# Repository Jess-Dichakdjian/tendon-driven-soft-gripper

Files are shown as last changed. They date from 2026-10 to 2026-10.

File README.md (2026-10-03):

# Tendon-Driven Soft Robotic Gripper

**Three-finger soft robotic gripper with antagonistic tendon actuation, silicone molding, suction-assisted grasping and pressure sensing**

Academic soft-robotics project focused on the design, fabrication and experimental validation of a compliant gripper capable of adapting to rigid, irregular, deformable and wet objects.

> **Status:** Completed academic team project  
> **Team size:** 6  
> **Main areas:** Soft robotics, mechanical design, silicone molding, tendon actuation, pressure sensing, prototyping and experimental validation

---

## At a Glance

| | |
|---|---|
| **Architecture** | Three soft silicone fingers arranged radially |
| **Actuation** | Six antagonistic tendons driven through a coaxial double-spool mechanism |
| **Control complexity** | One rotational input coordinates all three fingers |
| **Finger behaviour** | Active bidirectional bending |
| **Additional adhesion** | Palm-mounted silicone suction cup |
| **Sensing** | Suction-line pressure sensing |
| **Fabrication** | FDM-printed molds/frame + cast silicone fingers |
| **Materials** | Ecoflex 00-35 FAST and Dragon Skin 10 |
| **Testing** | Grasping, coordination, suction assistance and submerged-object retrieval |

---

# Project Overview

The objective was to develop a **three-finger soft robotic gripper** capable of secure and adaptive grasping across different object geometries and environmental conditions.

The design combined several complementary mechanisms:

```text
Soft Silicone Fingers
        +
Antagonistic Tendons
        +
Coaxial Double-Spool
        +
Palm Suction Cup
        +
Pressure Sensing
```

The resulting prototype was designed to support:

- external enveloping grasps
- internal expanding grasps
- irregular-object grasping
- deformable-object handling
- misaligned approaches
- suction-assisted holding
- wet and submerged object manipulation

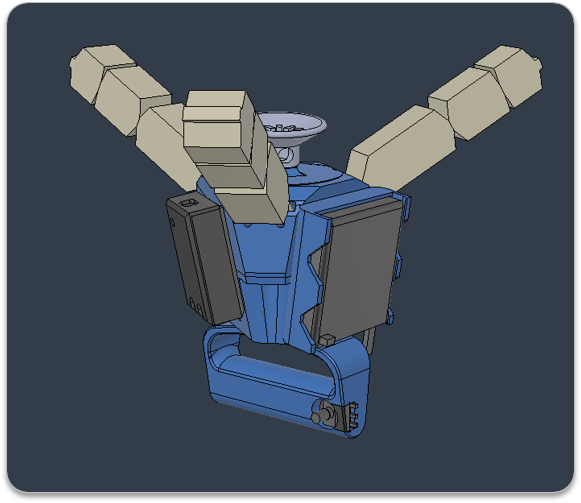
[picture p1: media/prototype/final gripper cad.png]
Final gripper CAD


[▶ View final gripper actuation](<media/prototype/final gripper actuation video.mp4>)

---

# My Contributions

This was a **six-person academic team project**.

My main contributions were:

### Concept & Prototyping

- contributed to the overall gripper concept and manipulation approach
- participated in iterative physical prototyping
- assisted with 3D printing of several prototype components
- contributed to final mechanical assembly

### Mold Preparation & Soft Fabrication

I took primary responsibility for the **mold-preparation stage**, including:

- preparing the molds before casting
- inserting cable guides / routing features
- applying mold-release treatment
- supporting the silicone casting process
- tendon/cable insertion after fabrication

### Pressure-Sensing System

I took primary responsibility for the **pressure-sensing subsystem**, from integration through working prototype testing.

The sensor was used to provide information about suction pressure and seal quality.

The implemented prototype used this as sensing/monitoring information.

A proposed future extension is to use the pressure signal in closed-loop control:

```text
Suction Pressure
      ↓
Detect Loss of Seal
      ↓
Increase Finger Grasp
      ↓
Reduce Risk of Object Drop
```

This automatic feedback behaviour was a **future-control concept**, not part of the final implemented controller.

### Experimental Validation

I participated with the team in the full experimental testing programme, including:

- finger motion testing
- three-finger coordination
- adaptive grasping
- suction-assisted grasping
- irregular and deformable object tests
- wet/submerged-object tests

---

# Mechanical Architecture

The gripper uses **three soft silicone fingers positioned approximately 120° apart**.

Each finger is designed for compliant bending and object adaptation.

The main mechanical elements are:

```text
Rigid 3D-Printed Frame
        │
        ├── Soft Finger ×3
        │     ├── Tendon A
        │     └── Tendon B
        │
        ├── Coaxial Double Spool
        │
        ├── Servo Actuation
        │
        └── Palm Suction Cup
              │
              └── Pressure Sensor
```

The soft fingers provide compliant contact, while the tendon mechanism provides active bending in both directions.

---

# Antagonistic Tendon Actuation

Each finger contains two antagonistic tendons.

The concept is analogous to opposing biological muscle groups:

```text
Tendon A pulls
     ↓
Finger bends in one direction

Tendon B pulls
     ↓
Finger bends in the opposite direction
```

A coaxial double-spool mechanism winds one tendon set while releasing the opposing set.

This allows:

- active flexion
- active extension
- coordinated finger motion
- low actuator count
- mechanical underactuation

One rotational input controls all six tendons and coordinates the three fingers.

[▶ View final gripper actuation](<media/prototype/final gripper actuation video.mp4>)

---

# Soft Finger Design

The finger geometry was designed to support large deformation while maintaining sufficient structural stability.

Important design features included:

- tapered finger geometry
- segmented finger structure
- bidirectional bending
- compliant silicone body
- rigid mounting at the finger base
- textured contact surfaces

The finger design also incorporated **hexagonal surface microstructures** inspired by biological wet-adhesion systems.

These textures were intended to help channel fluid away from the contact region and improve grip under wet conditions.

---

# Silicone Material Strategy

Two silicone materials were combined during fabrication.

### Ecoflex 00-35 FAST

Used for greater compliance and deformation.

### Dragon Skin 10

Used to provide additional structural support and shape stability.

The fabrication approach combined both materials to balance:

```text
Compliance
    ↕
Structural Stability
```

---

# Mold-Based Fabrication

The fingers were produced using custom 3D-printed molds.

The fabrication process included:

```text
CAD Mold Design
      ↓
3D Printing
      ↓
Cable-Guide Preparation
      ↓
Mold Release
      ↓
Silicone Mixing
      ↓
Separate Casting
      ↓
Partial Curing
      ↓
Mold Combination
      ↓
Final Curing
      ↓
Demolding
      ↓
Flash Removal
      ↓
Tendon Insertion
```

## Mold Preparation

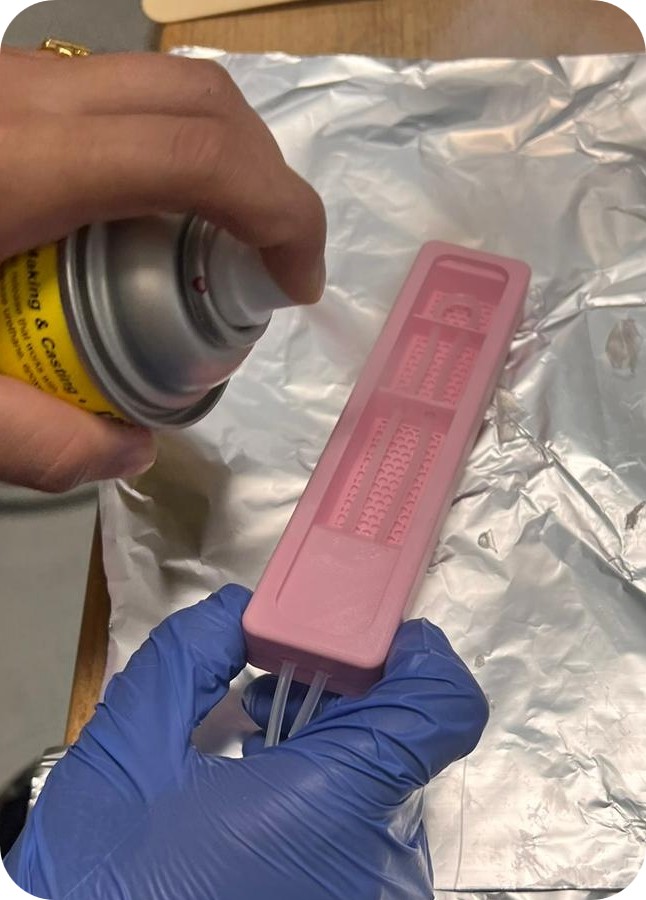
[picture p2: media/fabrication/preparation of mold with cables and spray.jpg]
Mold preparation


Cable guides were inserted to constrain tendon routing and reduce friction before the silicone was cast.

## Silicone Mixing

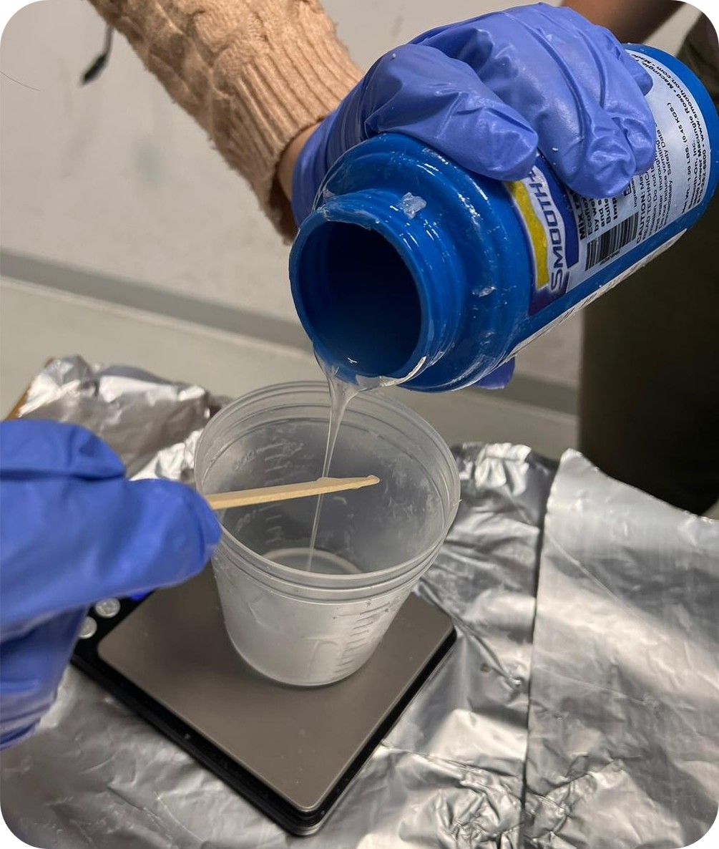
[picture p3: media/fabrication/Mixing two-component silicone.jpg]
Silicone mixing


## Two-Material Casting

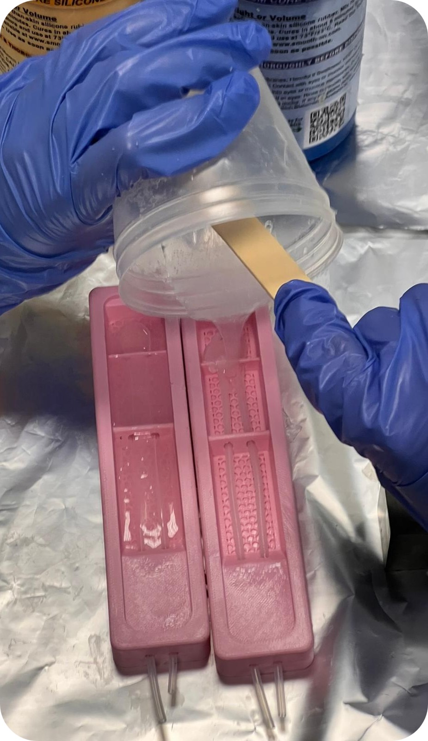
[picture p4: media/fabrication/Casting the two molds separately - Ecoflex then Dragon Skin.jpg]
Ecoflex and Dragon Skin casting


## Final Curing

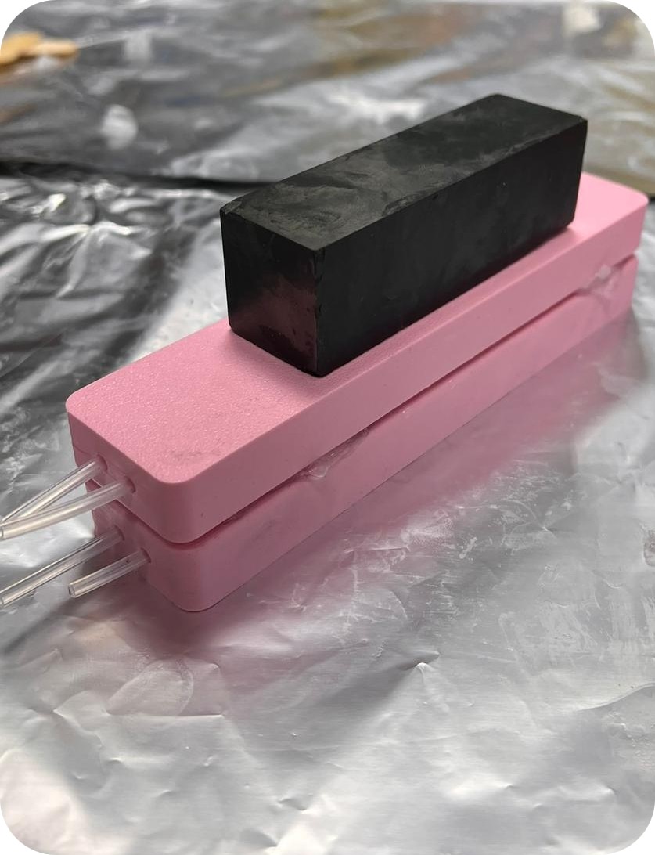
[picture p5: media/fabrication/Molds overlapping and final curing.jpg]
Molds overlapping for final curing


## Demolded Finger

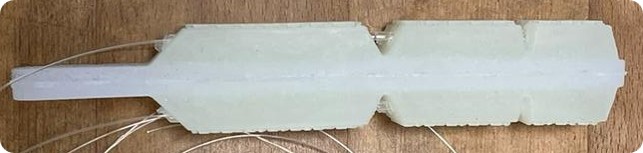
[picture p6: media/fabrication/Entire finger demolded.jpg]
Demolded soft finger


---

# Palm Suction System

A compliant silicone suction cup was integrated into the palm to complement the finger grasp.

The two mechanisms serve different roles:

```text
Soft Fingers
    ↓
Distributed Contact
+
Shear Stability

Suction Cup
    ↓
Normal Adhesion
```

When a suitable seal is formed, the suction cup provides additional resistance to pull-off forces.

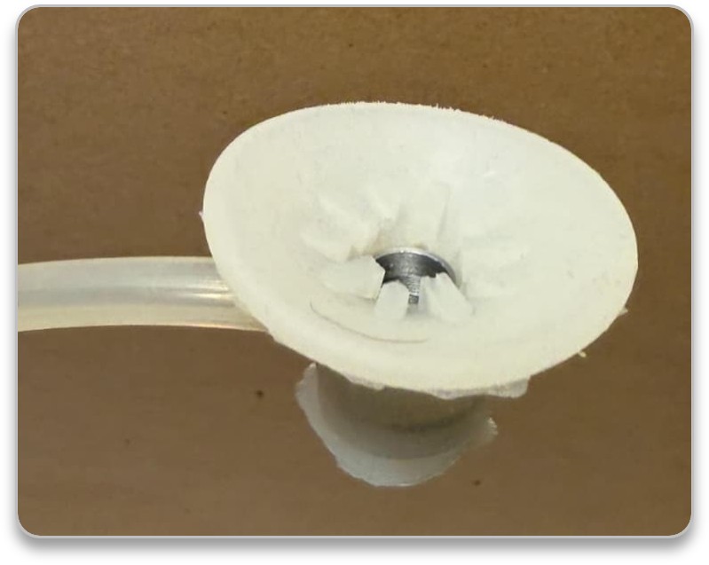
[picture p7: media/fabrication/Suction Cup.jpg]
Suction cup


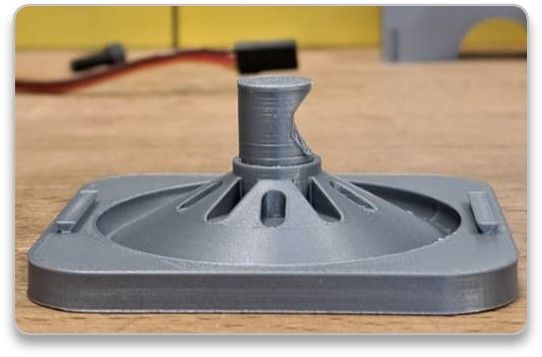
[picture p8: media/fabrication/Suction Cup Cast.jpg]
Cast suction cup


[▶ View suction-cup mold / fabrication concept](<media/fabrication/Suction Cup Casting exploded view.mp4>)

---

# Pressure Sensing

The suction line includes a pressure sensor.

The implemented sensing system provided information about the pressure level and therefore the quality of the suction seal.

This is particularly useful because suction performance depends strongly on:

- object geometry
- surface roughness
- contact alignment
- leakage
- seal quality

The pressure sensing worked on the physical prototype.

The current system uses the reading primarily as information.

A future closed-loop version could use pressure loss as a control trigger:

```text
Pressure Drop
     ↓
Possible Seal Loss
     ↓
Command Stronger Finger Closure
     ↓
Maintain Object Stability
```

That automatic response was **not implemented in the final prototype**.

---

# CAD & Mechanical Design

The repository includes both native SolidWorks files and a STEP export.

```text
cad/
├── solidworks/
│   ├── base.SLDPRT
│   ├── mold_fingers_fill_patt_v3_noBump.SLDPRT
│   ├── mold_fingers_fill_patt_v3_noBump_FINGER.SLDPRT
│   ├── molds_preview.SLDASM
│   └── soft_project_assembly.SLDASM
│
└── step/
    └── AssemblySoft.step
```

The STEP model provides a more software-independent representation of the mechanical assembly.

## Final CAD

Final gripper CAD

## Frame / Internal Layout

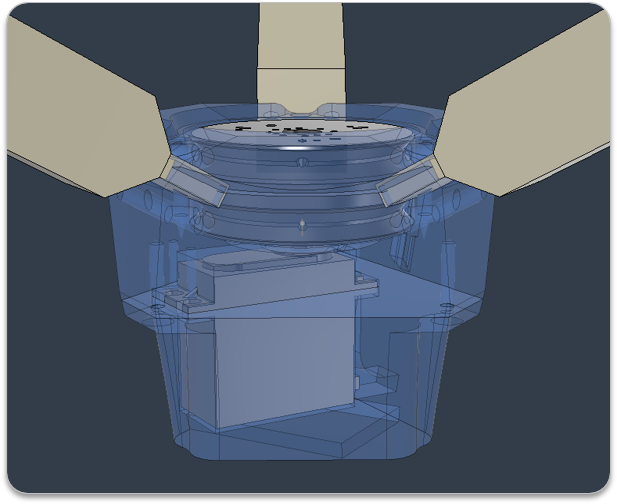
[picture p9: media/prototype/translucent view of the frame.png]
Translucent frame view


[▶ View exploded assembly animation](<media/prototype/final gripper exploded view.mp4>)

---

# Experimental Validation

Testing focused on verifying the gripper's key functional behaviours.

---

## 1. Bidirectional Finger Motion

The antagonistic tendons were tested for:

- flexion
- extension
- return toward neutral
- repeatability under repeated commands

The mechanism successfully demonstrated active bidirectional bending.

---

## 2. Three-Finger Coordination

The double-spool transmission was tested to verify whether all three fingers moved together under a single rotational input.

Evaluation focused on:

- simultaneous motion onset
- consistent opening/closing direction
- final finger curvature
- inter-finger timing differences

The prototype achieved coordinated three-finger motion.

Minor asymmetry was observed due to tendon friction and pretension differences.

---

# Adaptive Grasping Tests

Several grasp configurations were tested.

## External Enveloping Grasp

[▶ External enveloping grasp](<media/testing/EXTERNAL ENVELOPING GRASP.mp4>)

## Internal Expanding Grasp

[▶ Internal expanding grasp](<media/testing/INTERNAL EXPANDING GRASP.mp4>)

## Deformable / Flexible Object

[▶ Deformable-object test](<media/testing/DEFORMABLE-FLEXIBLE OBJECT.mp4>)

## Irregular Object

[▶ Irregular-object test](<media/testing/IRREGULAR OBJECT.mp4>)

## Misaligned Approach

[▶ Misaligned grasp approach](<media/testing/MISALIGNED APPROACH.mp4>)

These experiments demonstrated how compliance allows the fingers to adapt to shape and alignment variation without requiring exact geometric contact planning.

---

# Suction-Assisted Grasping

The palm suction cup was evaluated as an auxiliary adhesion mechanism.

[▶ Suction-assisted grasping](<media/testing/Suction-Assisted Grasping.mp4>)

The tests showed that suction can complement the soft fingers when an adequate seal is available.

The fingers contribute distributed contact and lateral stability, while suction contributes additional normal adhesion.

---

# Wet / Submerged Testing

Wet manipulation was an important target scenario because the finger texture and suction concept were inspired partly by biological attachment mechanisms.

## Single Object Retrieval

[▶ Single submerged-object retrieval](<media/testing/Single submerged object retrieval.mp4>)

## Multiple Object Retrieval

[▶ Multiple submerged-object retrieval](<media/testing/Multiple submerged object retrieval.mp4>)

The prototype was able to perform submerged grasping demonstrations using the compliant fingers and textured contact surfaces.

---

# Validation Against Design Objectives

| Objective | Outcome |
|---|---|
| Active bidirectional bending | ✅ Achieved |
| One-input three-finger coordination | ✅ Achieved |
| Adaptive grasping across different geometries | ✅ Achieved |
| Suction-assisted holding | ✅ Achieved |
| Physical silicone-finger fabrication | ✅ Achieved |
| Wet/submerged grasp demonstrations | ✅ Demonstrated |
| Working pressure sensing | ✅ Implemented |
| Automatic pressure-based grasp tightening | ❌ Future work |
| Quantitative grasp-force validation | ❌ Not performed |
| Closed-loop autonomous suction control | ❌ Not implemented |

The project therefore demonstrated the proposed low-complexity hybrid grasping architecture while also identifying clear areas for further development.

---

# Limitations

The prototype exhibited several expected limitations of tendon-driven soft systems.

### Tendon Transmission Variability

Cable friction, slack and pretension differences can create:

- small delays
- asymmetric finger motion
- different final curvatures

### Fabrication Variability

Manual silicone fabrication can introduce:

- bubbles
- mold tolerances
- material inconsistencies
- bending asymmetry

### Suction Seal Dependence

Suction performance depends strongly on contact geometry and seal quality.

### Primarily Qualitative Validation

Testing demonstrated functional success, but the project did not include a full quantitative benchmark of:

- grasp force
- payload capacity
- pull-off force
- bending angle
- success rate
- cycle durability

---

# Future Work

The clearest next steps are:

### Closed-Loop Pressure Feedback

Use the existing pressure sensing as feedback for automatic grasp adaptation:

```text
Pressure falls
    ↓
Detect reduced suction
    ↓
Increase finger tension
    ↓
Maintain grasp
```

### Automatic Vacuum Generation

Replace the manually driven suction source with a compact controllable pump.

### Improved Tendon Routing

Add:

- lower-friction guides
- adjustable tensioners
- better cable anchoring

### More Repeatable Silicone Fabrication

Potential improvements include:

- improved mold tolerances
- vacuum degassing
- standardized curing
- more repeatable material dosing

### Quantitative Testing

Future experiments should measure:

- bending angle
- grasp force
- payload
- suction pull-off force
- grasp success rate
- repeatability
- durability over repeated cycles

---

# Repository Structure

```text
tendon-driven-soft-gripper/
│
├── README.md
│
├── cad/
│   ├── solidworks/
│   └── step/
│
├── docs/
│   └── presentation/
│
└── media/
    ├── fabrication/
    ├── prototype/
    └── testing/
```

---

# Project Presentation

The final team presentation is included here:

```text
docs/presentation/Group 2 - Soft Robotics Project Submission-compressed.pdf
```

It contains the complete project development process, design rationale, manufacturing workflow and testing programme.

---

# Skills Demonstrated

This project provides evidence of experience in:

- soft robotics
- mechanical prototyping
- tendon-driven actuation
- compliant mechanisms
- underactuated robotic systems
- SolidWorks
- CAD
- FDM 3D printing
- mold design
- silicone casting
- Ecoflex
- Dragon Skin
- tendon routing
- mechanical assembly
- pressure sensing
- suction systems
- sensor integration
- experimental testing
- wet-environment manipulation
- robotic grasping
- design iteration
- hardware integration

---

# Team Work & Attribution

This repository represents a **six-person academic team project**.

The complete system, CAD, prototype and validation programme were developed collaboratively.

The **My Contributions** section above identifies the areas in which I had direct responsibility or significant hands-on involvement.

In particular, I took primary responsibility for:

- mold preparation
- tendon/cable insertion support
- pressure-sensor integration and testing

and contributed to:

- project concept development
- physical prototyping
- 3D printing
- assembly
- experimental validation

Electronics and actuator-control development were primarily handled by other team members, with limited input from me.

---

# Project Status

✅ **Completed academic soft-robotics project**

The physical prototype was fabricated and successfully demonstrated:

- active bidirectional finger motion
- coordinated three-finger actuation
- adaptive grasping
- suction-assisted holding
- pressure sensing
- wet/submerged object retrieval

The next development stage would focus on **closed-loop sensing and control, improved fabrication repeatability and quantitative performance evaluation**.

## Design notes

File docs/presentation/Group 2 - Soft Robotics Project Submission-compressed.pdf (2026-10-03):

# Soft Robotics – Final project

Presented by (Group 2)
Andrea Radicetti
Ege Sarp Dengizmen
Giulia Papini
Jessica Dichakdjian
Tommaso Servillo
Tony Al Helou

Presented to
Professor Barbara Mazzolai Tommaso Scudeletti
Presented on
23/07/2026

# INTRODUCTION

2

# Project Overview

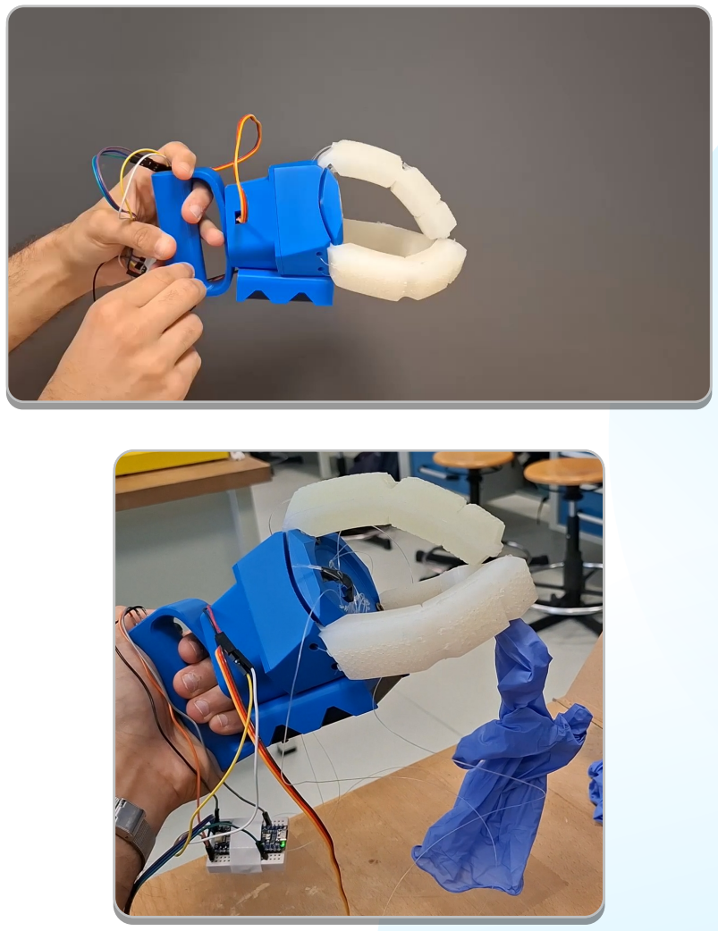
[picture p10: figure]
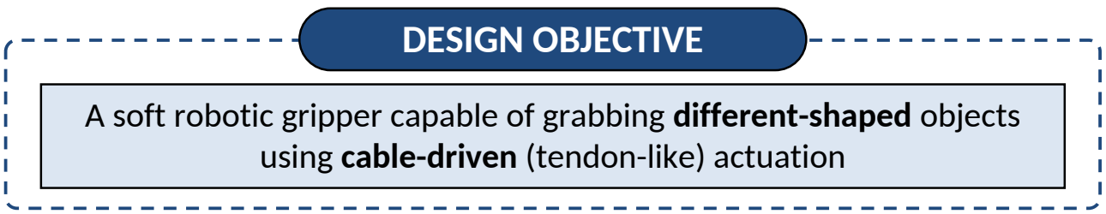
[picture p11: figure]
using cable-driven (tendon-like) actuation; DESIGN OBJECTIVE

A soft robotic gripper capable of grabbing different-shaped objects

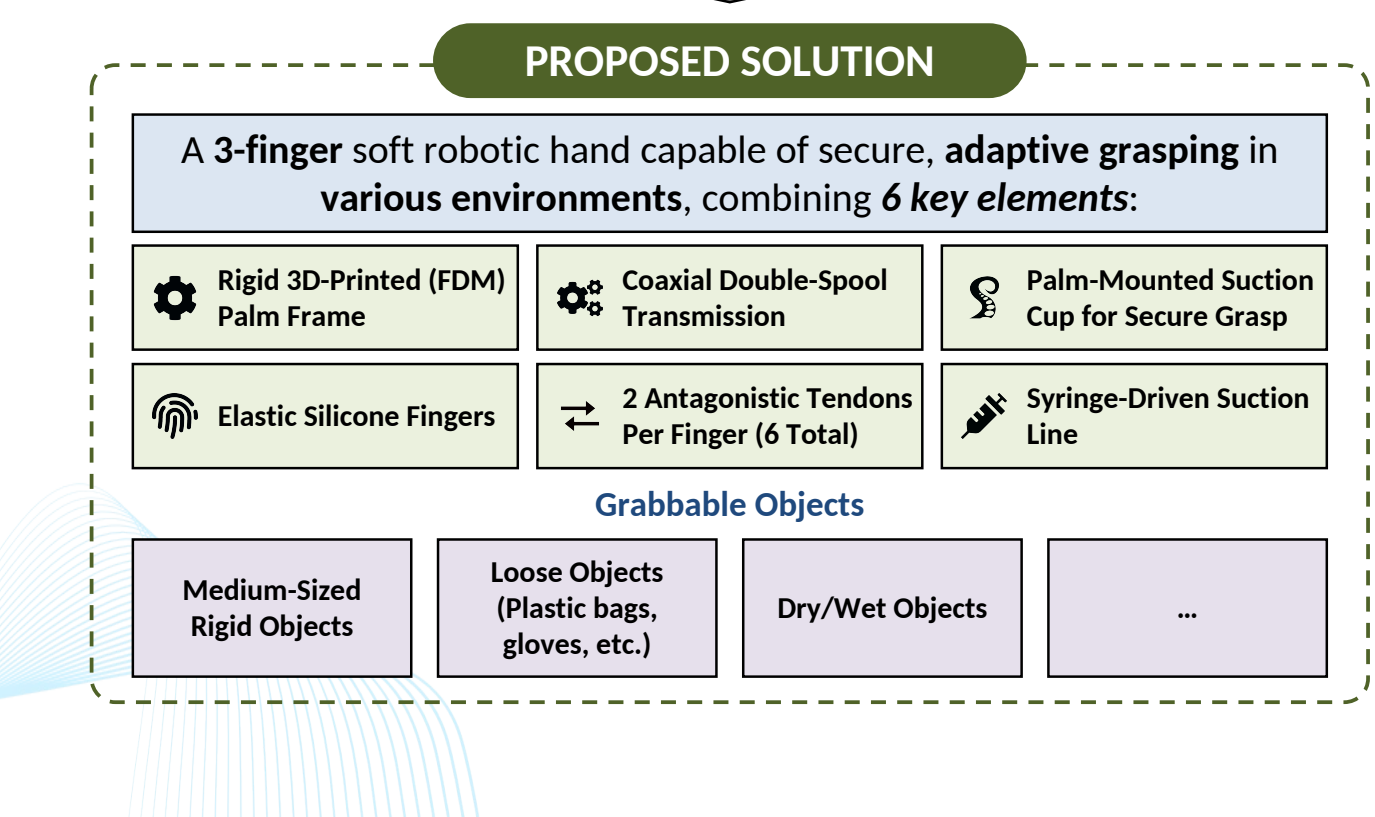
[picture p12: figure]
Medium-Sized Rigid Objects; Loose Objects (Plastic bags, gloves, etc.); Dry/Wet Objects; PROPOSED SOLUTION; Rigid 3D-Printed (FDM) Palm Frame; Coaxial Double-Spool Transmission; Palm-Mounted Suction Cup for Secure Grasp; Elastic Silicone Fingers; 2 Antagonistic Tendons; Per Finger (6 Total); Syringe-Driven Suction Line; Grabbable Objects

A 3-finger soft robotic hand capable of secure, adaptive grasping in various environments, combining 6 key elements:

3

# Why use Soft Grasping?

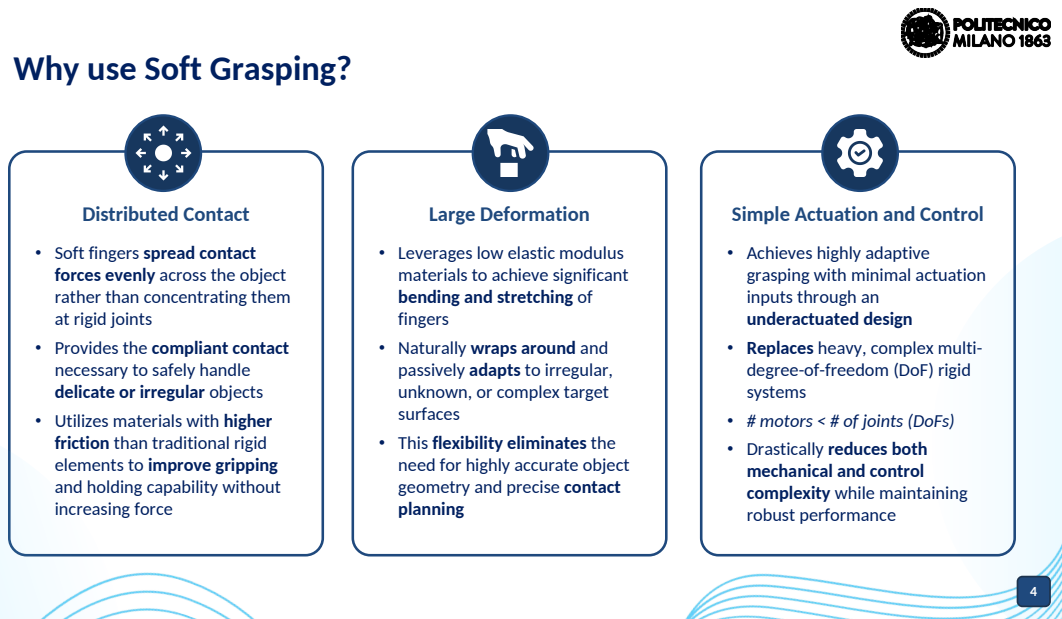
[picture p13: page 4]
Distributed Contact; Large Deformation; Simple Actuation and Control

• Soft fingers spread contact
forces evenly across the object
rather than concentrating them
at rigid joints
• Provides the compliant contact
necessary to safely handle
delicate or irregular objects
• Utilizes materials with higher
friction than traditional rigid
elements to improve gripping
and holding capability without
increasing force

• Leverages low elastic modulus
materials to achieve significant
bending and stretching of
fingers
• Naturally wraps around and
passively adapts to irregular,
unknown, or complex target
surfaces
• This flexibility eliminates the
need for highly accurate object
geometry and precise contact
planning

• Achieves highly adaptive
grasping with minimal actuation
inputs through an
underactuated design
• Replaces heavy, complex multi-
degree-of-freedom (DoF) rigid
systems
• # motors < # of joints (DoFs)
• Drastically reduces both
mechanical and control
complexity while maintaining
robust performance

# STATE OF THE ART

5

# State of the Art – Tendon-Driven Soft Fingers

Working
Principle
- Transmits forces from a motor by shortening or lengthening flexible cables routed directly through the silicone fingers (in series or parallel)
- Produces natural, adaptive bending and grasping around diverse geometries
- Eliminates the need for rigid joint linkages or internal skeletons for each finger

Trade-offs &
Limitations
- Hosting cable tensioning motors outside the soft structure provides a fast response with low system inertia, weight, and volume
- Forces subject the elastomeric fingers to friction, mechanical wear, and physical tear – tendon elasticity wears down -> hysteresis and creep
- Highly nonlinear (no universal formula)

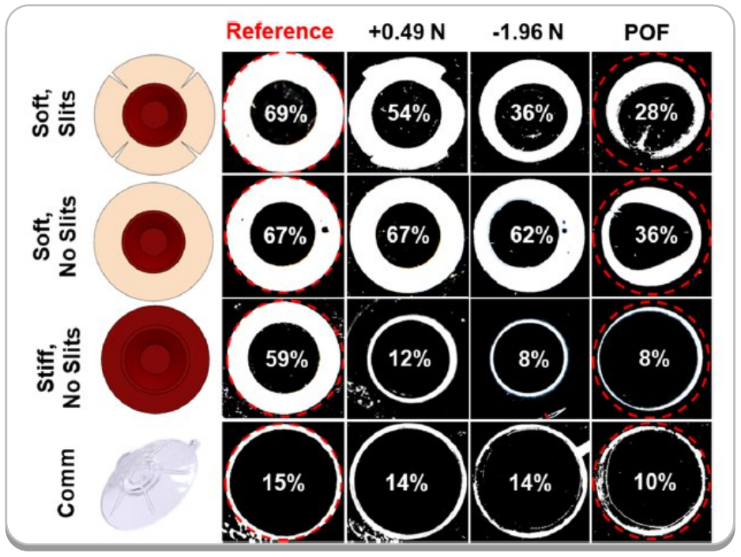
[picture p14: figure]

[“Reversible adhesion to rough surfaces both in and out of water, inspired by the clingfish suction disc”, J.A.Sandoval et al., 2019]

# State of the Art – Suction Cup

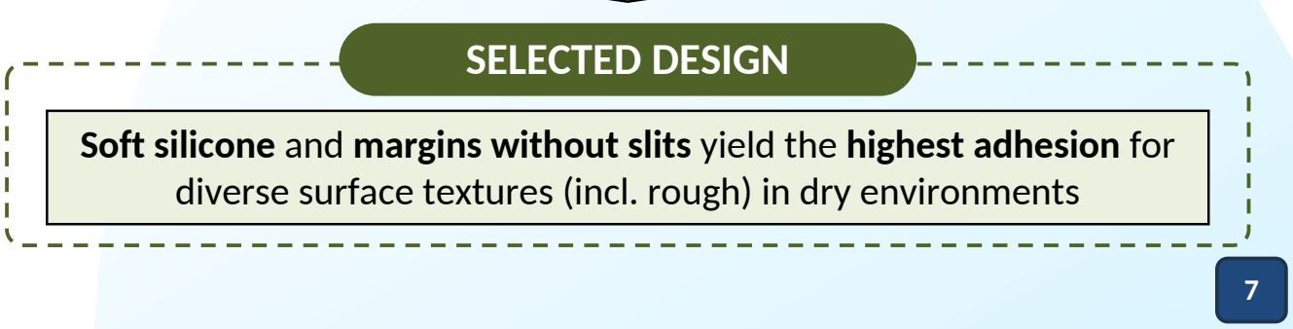
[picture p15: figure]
SELECTED DESIGN

Soft silicone and margins without slits yield the highest adhesion for diverse surface textures (incl. rough) in dry environments

Adhesion is generated through a pressure differential between the inner cavity and the surrounding environment

Performance varies depending on the design parameters

The suction cup is pressed against the object to expel fluid or air from the internal chamber and initiate the attachment seal
Functions as an additional adhesion mechanism that complements the gripping forces of the fingers, and can adapt to surface shape and curvature as long as the radial margins/boundaries are firmly sealed
Suction Cup Geometry | Margin Slits | Material Stiffness | …

WORKING PRINCIPLE

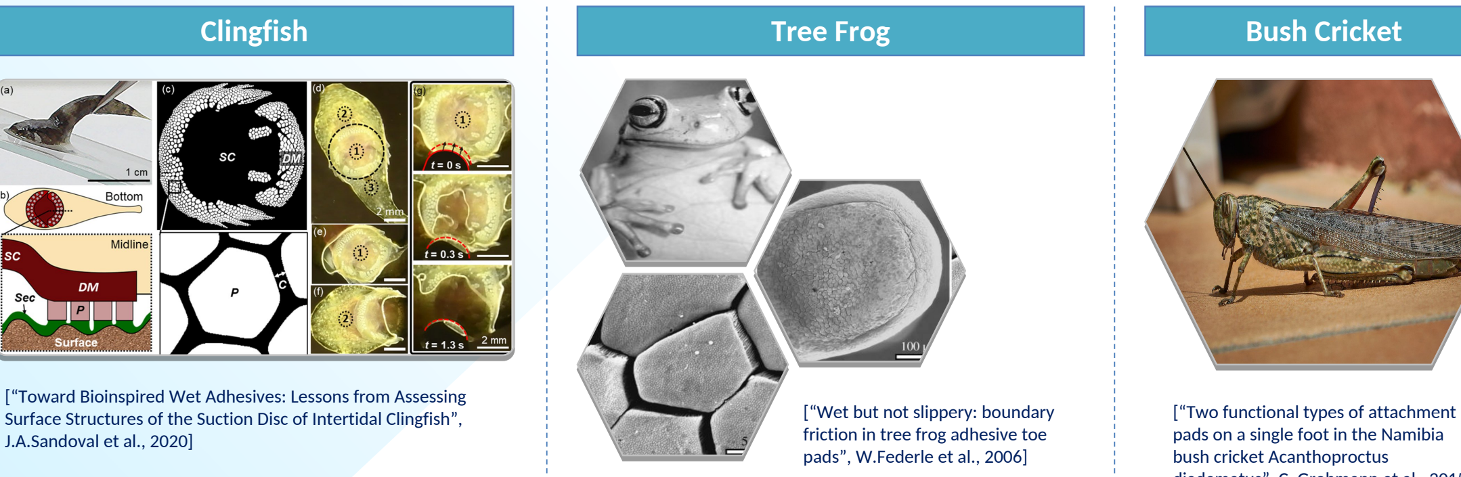
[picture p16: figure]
J.A.Sandoval et al., 2020]; Clingfish; Bush Cricket; [“Wet but not slippery: boundary friction in tree frog adhesive toe pads”, W.Federle et al., 2006]; Tree Frog; [“Two functional types of attachment pads on a single foot in the Namibia bush cricket Acanthoproctus
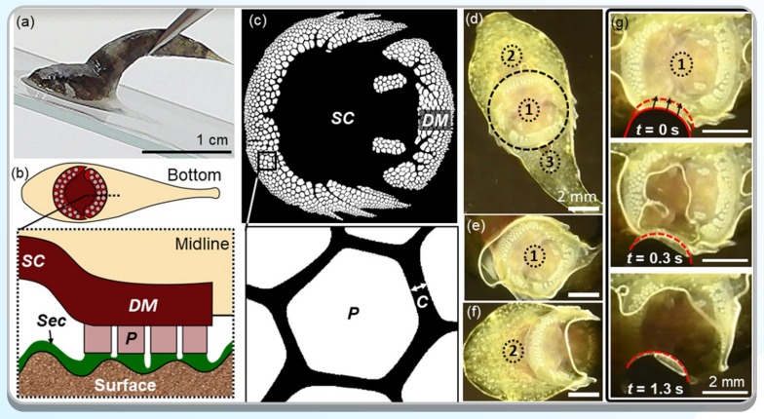
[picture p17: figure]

[“Toward Bioinspired Wet Adhesives: Lessons from Assessing Surface Structures of the Suction Disc of Intertidal Clingfish”,

8

# State of the Art – Hexagonal Surface Textures

Biological
Inspiration
- Hexagonal microstructures are found on the attachment pads of the clingfish, tree frog, and bush-cricket
- Channels away boundary fluids from surfaces through micro-grooves between hexagon shapes to prevent hydrodynamic lubrication (hydroplaning) and the formation of a slippery lubricating fluid film
- They allow animals to maintain a secure, high-friction contact interface even when fully submerged or interacting with highly lubricated wet objects

diadematus”, C. Grohmann et al., 2015]

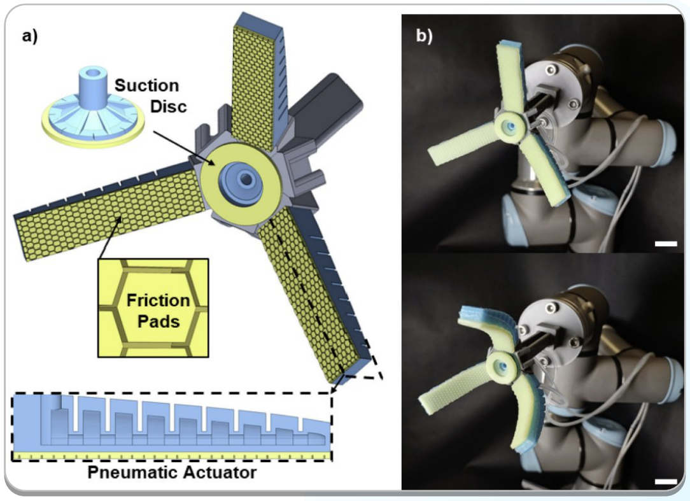
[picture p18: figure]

[“Combining Suction and Friction to Stabilize a Soft Gripper to Shear and Normal Forces, for Manipulation of Soft Objects in Wet Environments”, J.A.Sandoval et al., 2022]
9

# State of the Art – Combination of Soft Gripper and Suction

CHALLENGING WET ENVIRONMENTS Boundary fluids act as a lubricant between soft fingers and
target surfaces, reducing friction and causing hydrodynamic
slipping during object manipulation HYBRID APPROACH
- Combination of texture micro-channels and central palm suction cup to divert boundary fluids and re-establish direct between fingers and surface material
- Two complementary force mechanisms where the suction cup handles normal pull-off resistance and the fingers provide lateral shear stability
Approach achieves higher tolerance under combined normal and shear loads than either suction or soft fingers can provide alone

# DESIGN

10

# From reference to our idea

STARTING POINT | OUR IDEA IMPLEMENTATION

11

Underactuated soft gripper: tendon-driven soft finger, one motor, one DOF, passive elastic recovery.

Bio-inspired design solutions: suction disk (like clingfish) with surface texture for enhanced grip + shape of human finger

Palm suction cup for enhanced grasping reliability.

Hexagonal texture on finger surfaces for improved wet grip.

Three-finger gripper with two antagonistic tendons per finger → active bidirectional bending (via Double-spool mechanism).

# Design - Finger

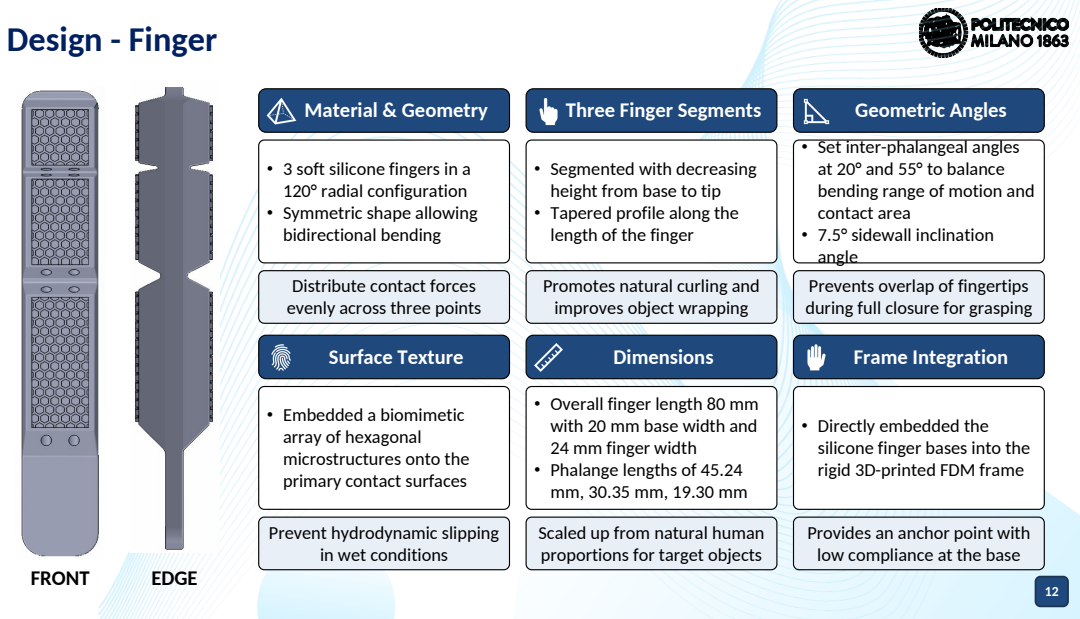
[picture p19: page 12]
FRONT; EDGE

Material & Geometry
• 3 soft silicone fingers in a
120° radial configuration
• Symmetric shape allowing
bidirectional bending
Distribute contact forces
evenly across three points
Surface Texture
• Embedded a biomimetic
array of hexagonal
microstructures onto the
primary contact surfaces
Prevent hydrodynamic slipping
in wet conditions

Three Finger Segments
• Segmented with decreasing
height from base to tip
• Tapered profile along the
length of the finger
Promotes natural curling and
improves object wrapping
Dimensions
• Overall finger length 80 mm
with 20 mm base width and
24 mm finger width
• Phalange lengths of 45.24
Scaled up from natural human
proportions for target objects

Geometric Angles
• Set inter-phalangeal angles
at 20° and 55° to balance
bending range of motion and
contact area
• 7.5° sidewall inclination
angle
Prevents overlap of fingertips
during full closure for grasping
Frame Integration
• Directly embedded the
silicone finger bases into the
rigid 3D-printed FDM frame
Provides an anchor point with
low compliance at the base

# Design – Antagonistic Cable Pair

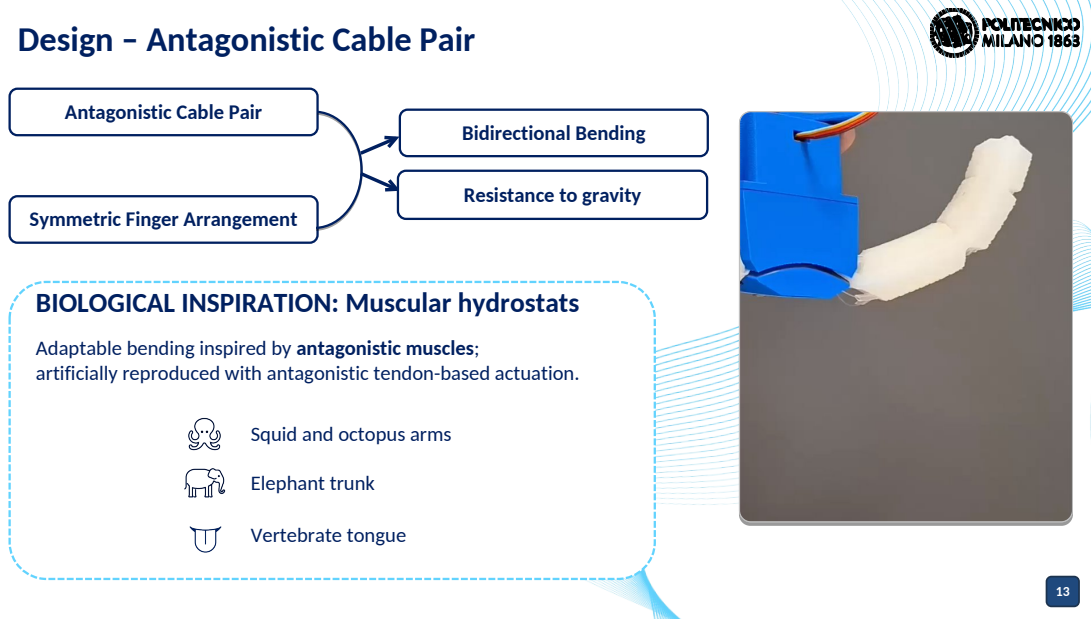
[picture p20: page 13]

Antagonistic Cable Pair

Bidirectional Bending
Resistance to gravity

Symmetric Finger Arrangement
BIOLOGICAL INSPIRATION: Muscular hydrostats
Adaptable bending inspired by antagonistic muscles;
artificially reproduced with antagonistic tendon-based actuation.

Squid and octopus arms
Elephant trunk
Vertebrate tongue

# Design – Actuation

14

Coaxial double-spool design
Two coaxial spools with oppositely wound cable pairs, as one set of cables winds, the opposing set unwinds.

Single DOF control (1 rotational input)
One spool rotation angle drives 6 cables and 3 fingers simultaneously, achieving full open/close behavior with minimal actuation and control hardware.

Arduino-driven actuation
Servo motor is driven through a potentiometer.

Parallel wire arrangement
To mitigate effects of built-up friction along the whole wire line a series arrangement would have.

# Design – Palm Suction Cup

15

# Design – Frame

Moldable Design
The suction cup was designed considering the molding process and flow of silicone
Ribbed Center
The ribbed center achieves structural integrity, controlled deformation, controlled airflow
Pressure Sensing
The suction line is integrated with a pressure sensor.

Compact Design
The frame geometry is designed to be as compact as possible to increase reachability of the gripper
Modular Design
The frame is modular and allows for future customization. The frame can be attached with a handle or can be attached to a robot arm. The palm of the gripper houses a slot for an optional suction cup. There are also slots for the battery and electronic components along the sides of the frame.

# Hardware implementation

16

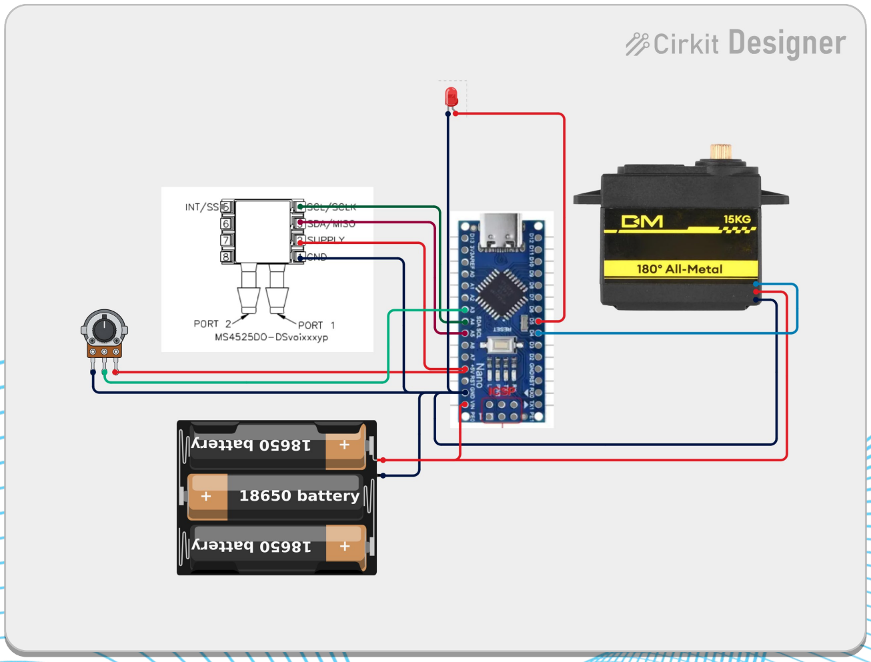
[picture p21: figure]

### 1 Rigid 3D-printed frame 2 Silicone elastomer fingers (×3)

3

Antagonistic tendons
(×2 per finger)

### 4 Coaxial double spool

5

Palm suction cup with syringe-driven vacuum line

### 6 Pressure sensor

# Robot Architecture

17

# Design - Frame

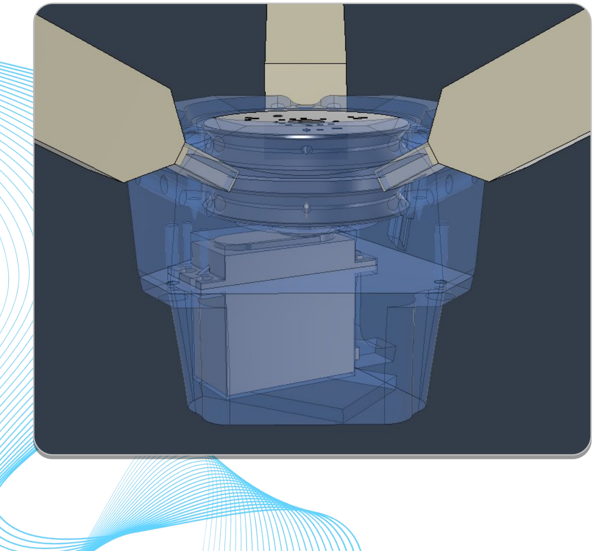
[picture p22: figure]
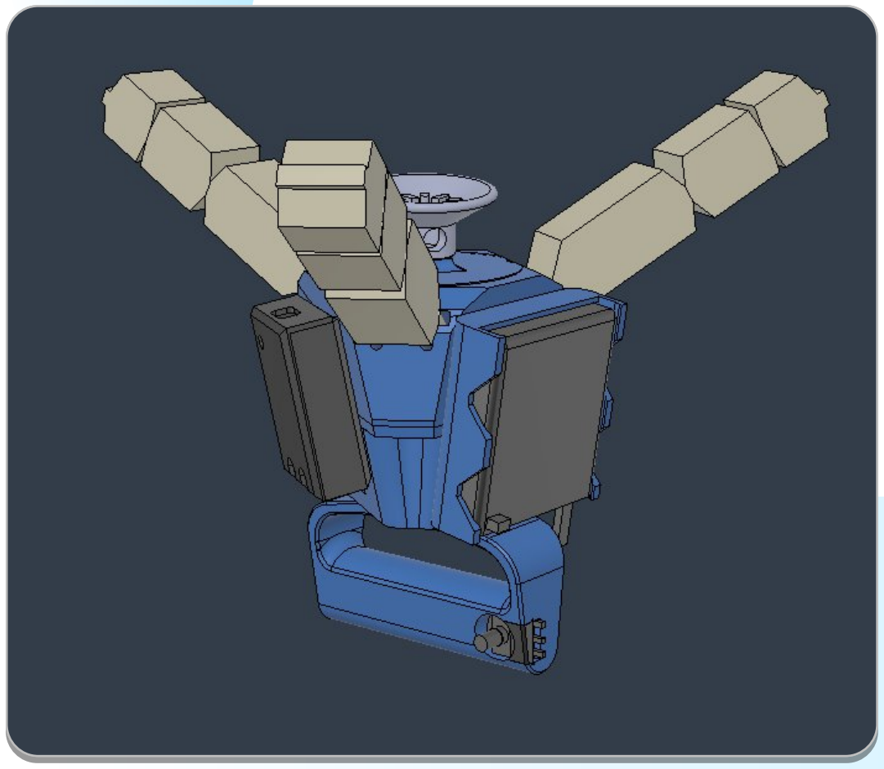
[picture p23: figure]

18

# MANUFACTURING

19

# Mold-Based Silicone Casting: Finger

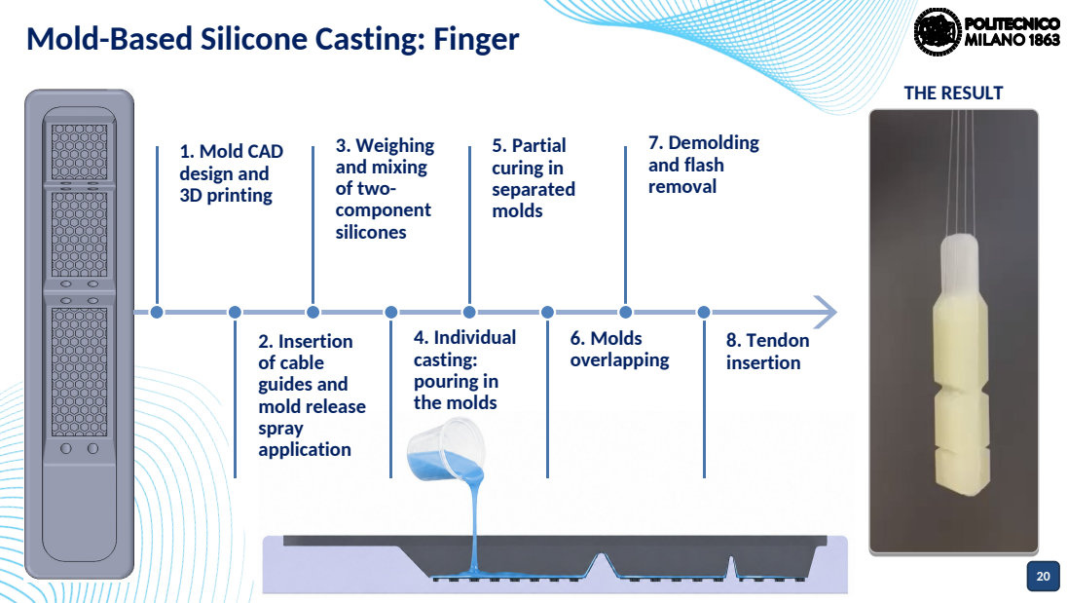
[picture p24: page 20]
1. Mold CAD design and 3D printing; 2. Insertion of cable guides and mold release spray application; 3. Weighing and mixing of two- component silicones; 4. Individual casting: pouring in the molds; 5. Partial curing in separated molds; 6. Molds overlapping; 7. Demolding and flash removal; 8. Tendon insertion; THE RESULT

# Mold-Based Silicone Casting: Finger In-Lab Fabrication

2. | 3. | 4. | 6.

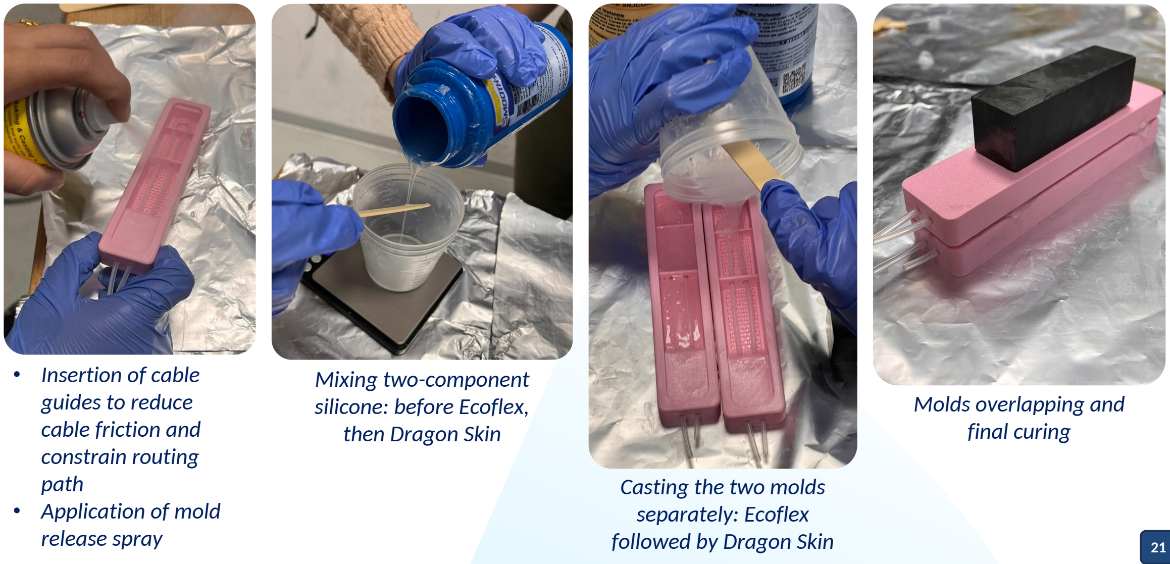
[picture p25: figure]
• Insertion of cable guides to reduce cable friction and constrain routing path • Application of mold release spray; Mixing two-component silicone: before Ecoflex, then Dragon Skin; Casting the two molds separately: Ecoflex followed by Dragon Skin; Molds overlapping and final curing

First prototype of a half of a finger

## LAYERING OF TWO SILICONE TYPES

# Mold-Based Silicone Casting: Finger In-Lab Fabrication

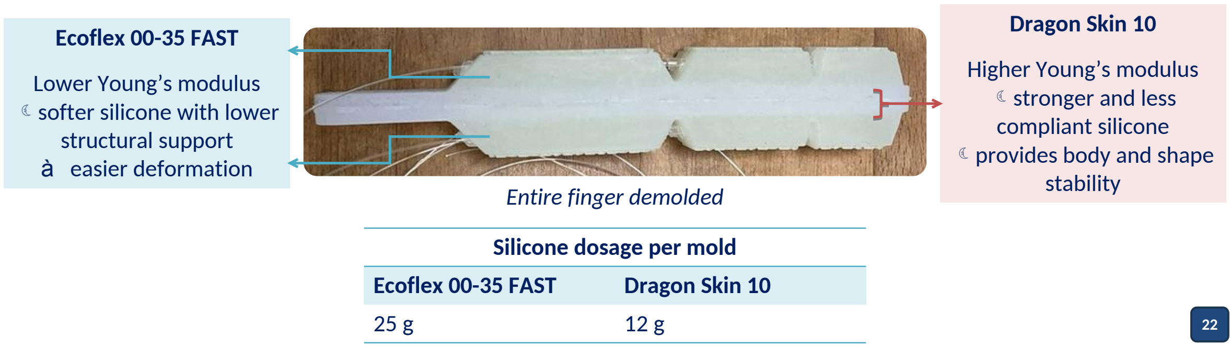
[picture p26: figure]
Entire finger demolded; Ecoflex 00-35 FAST Lower Young’s modulus softer silicone with lower structural support à easier deformation; Dragon Skin 10 Higher Young’s modulus stronger and less compliant silicone provides body and shape stability; Silicone dosage per mold; Ecoflex 00-35 FAST; Dragon Skin 10

# Mold-Based Silicone Casting: Suction Cup

## Modular mold: CAD design and 3D printing

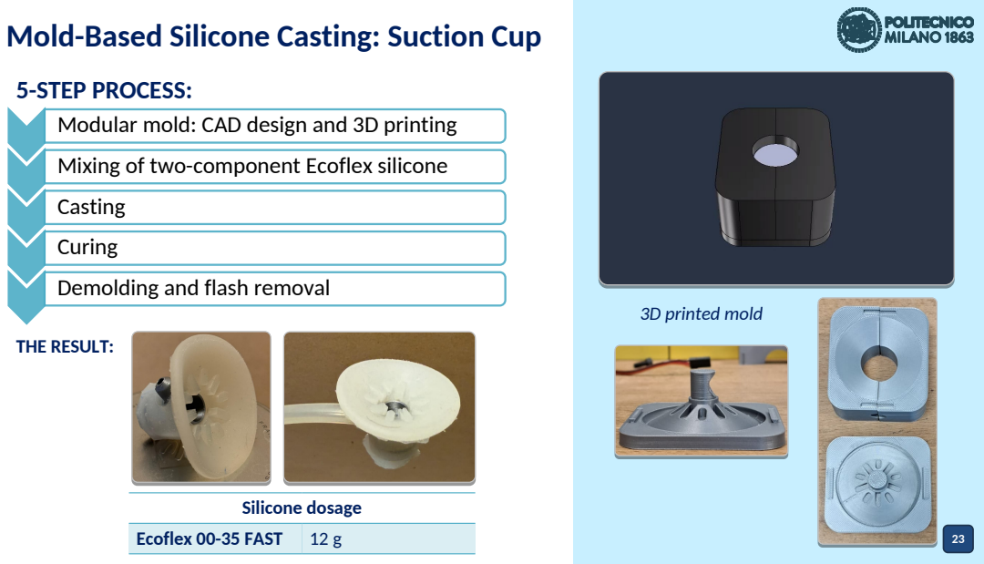
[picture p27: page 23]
3D printed mold; Silicone dosage; Ecoflex 00-35 FAST

5-STEP PROCESS:
Mixing of two-component Ecoflex silicone
Casting
Curing
Demolding and flash removal
THE RESULT:

# TESTING & VALIDATION

24

25

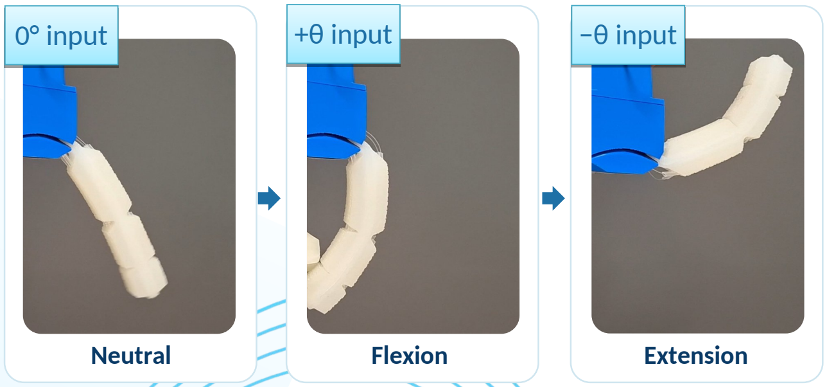
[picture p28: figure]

Repeated flexion–extension cycles under identical motor commands

# Single Finger Motion Test

AIM: Evaluating active bidirectional motion of a single antagonistic tendon-driven finger.

## MECHANICAL COUPLING: Coordinated Three-Finger Motion

# Three-Finger Coordination Test

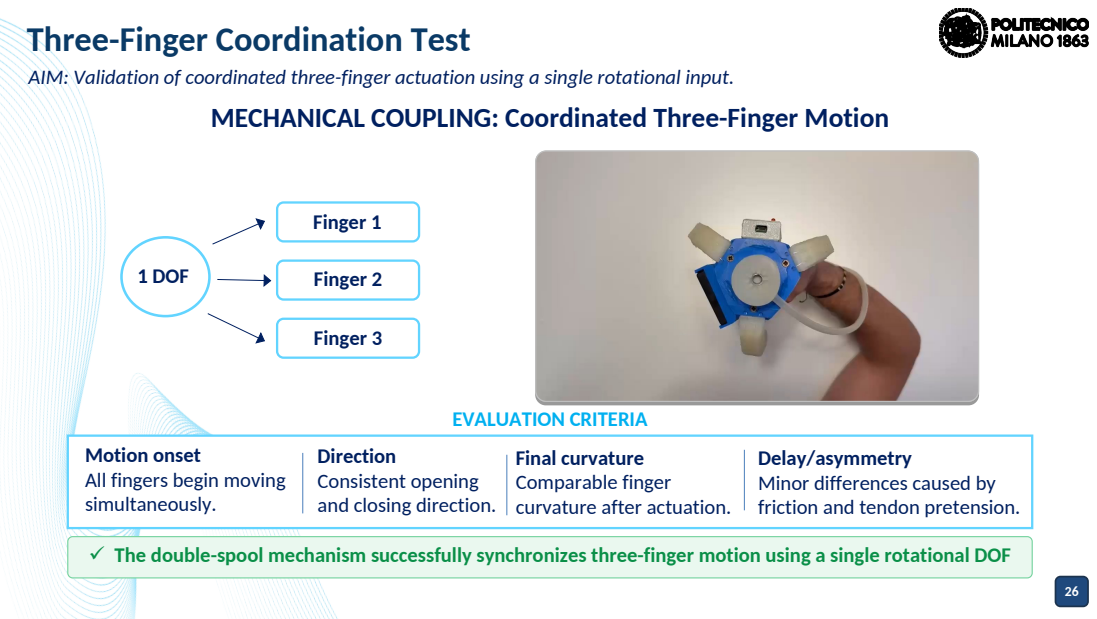
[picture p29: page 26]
Finger 1 Finger 2 Finger 3; 1 DOF

AIM: Validation of coordinated three-finger actuation using a single rotational input.

EVALUATION CRITERIA
Final curvature
Comparable finger
curvature after actuation.

Motion onset
All fingers begin moving
simultaneously.
The double-spool mechanism successfully synchronizes three-finger motion using a single rotational DOF

Direction
Consistent opening
and closing direction.

Delay/asymmetry
Minor differences caused by
friction and tendon pretension.

# Adaptive Grasping Test

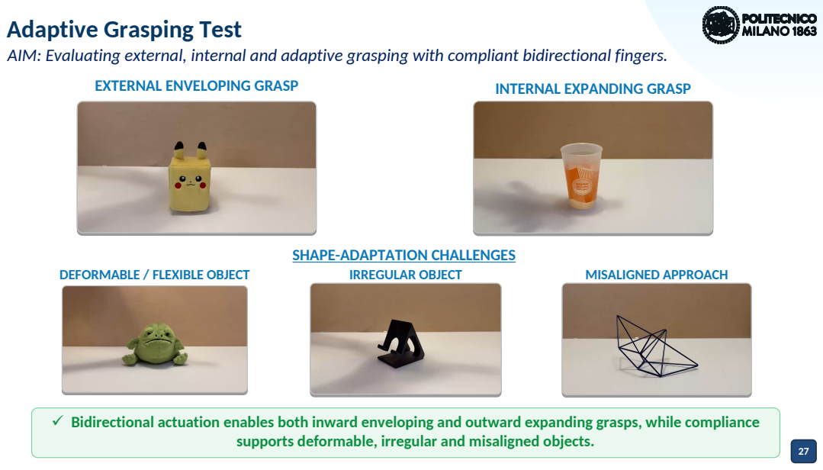
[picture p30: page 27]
EXTERNAL ENVELOPING GRASP; INTERNAL EXPANDING GRASP; DEFORMABLE / FLEXIBLE OBJECT; IRREGULAR OBJECT; MISALIGNED APPROACH

AIM: Evaluating external, internal and adaptive grasping with compliant bidirectional fingers.

SHAPE-ADAPTATION CHALLENGES

Bidirectional actuation enables both inward enveloping and outward expanding grasps, while compliance

supports deformable, irregular and misaligned objects.

# Suction-Assisted Grasping

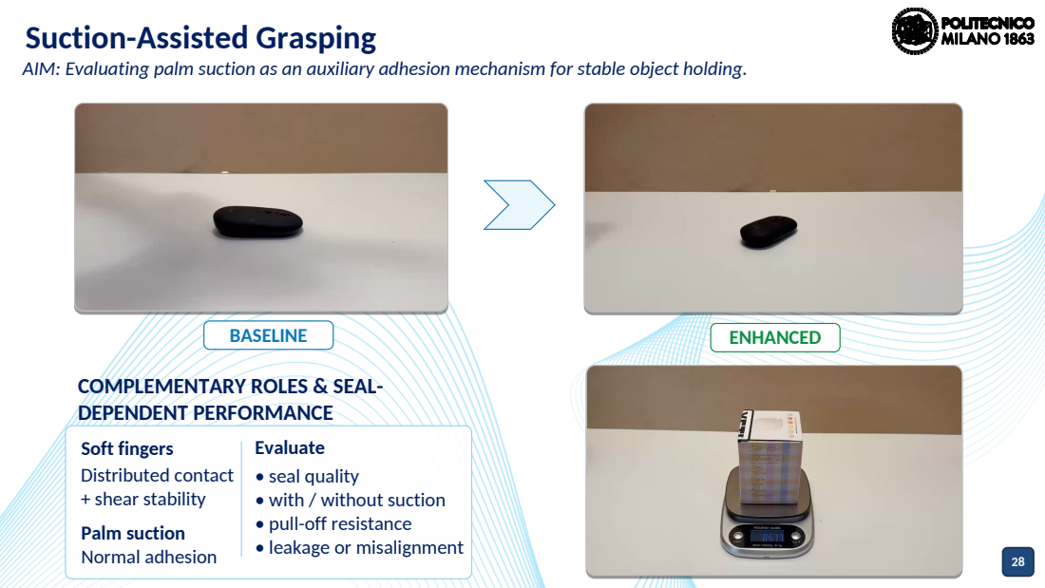
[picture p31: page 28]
BASELINE; ENHANCED

AIM: Evaluating palm suction as an auxiliary adhesion mechanism for stable object holding.

COMPLEMENTARY ROLES & SEAL-
DEPENDENT PERFORMANCE
Soft fingers
Distributed contact
+ shear stability
Palm suction
Normal adhesion

Evaluate
• seal quality
• with / without suction
• pull-off resistance
• leakage or misalignment

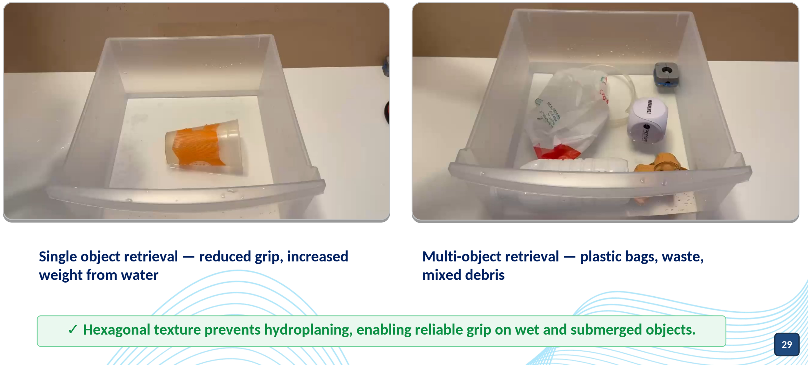
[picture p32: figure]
weight from water; mixed debris

Single object retrieval — reduced grip, increased

✓ Hexagonal texture prevents hydroplaning, enabling reliable grip on wet and submerged objects.

# Wet Environment Performance

AIM: Validating performance in wet conditions, the target scenario that motivated the hexagonal surface texture.

Multi-object retrieval — plastic bags, waste,

30

The prototype demonstrates the proposed low-complexity hybrid grasping concept: compliant fingers provide adaptation, the double spool provides coordination, and suction adds holding support when sealing is possible

# Validation Against Design Objectives

AIM: Connecting the experimental observations to the original prototype requirements.
DESIGN OBJECTIVE | VALIDATION OUTCOME
01 Active bidirectional bending | ACHIEVED
02 One-input three-finger coordination | ACHIEVED
03 Adaptive grasping across geometries | ACHIEVED
04 Suction-assisted holding | ACHIEVED

# CONCLUSION & FUTURE WORK

31

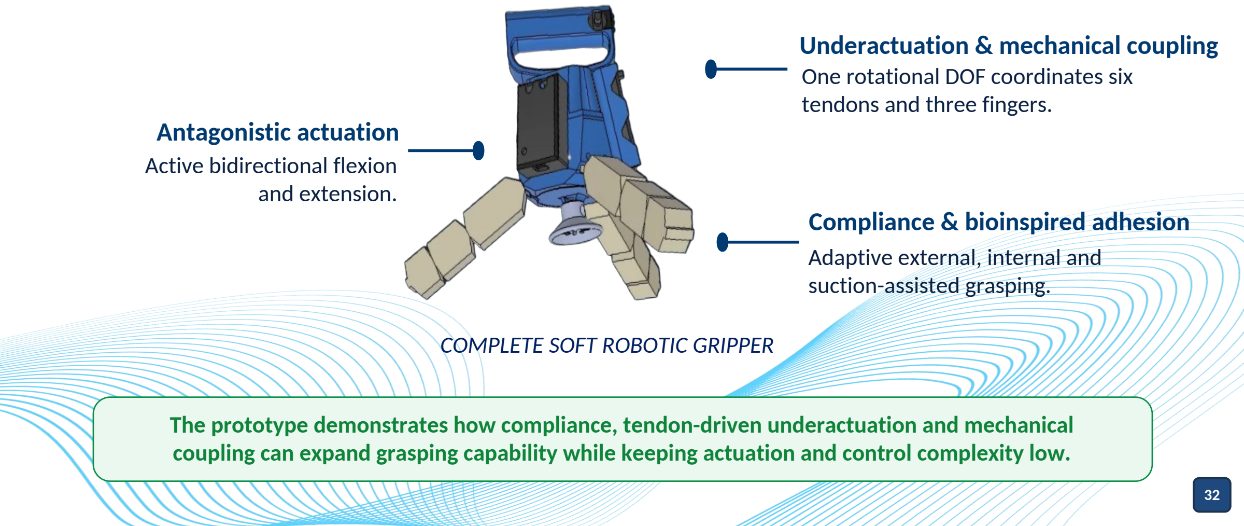
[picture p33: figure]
COMPLETE SOFT ROBOTIC GRIPPER; Antagonistic actuation Active bidirectional flexion and extension.; Underactuation & mechanical coupling One rotational DOF coordinates six tendons and three fingers.; Compliance & bioinspired adhesion Adaptive external, internal and suction-assisted grasping.

The prototype demonstrates how compliance, tendon-driven underactuation and mechanical coupling can expand grasping capability while keeping actuation and control complexity low.

# Conclusion

RESULT: Low-complexity soft grasping through compliance, bidirectional actuation and suction.

33

① Transmission variability
Cable friction, slack and pretension imbalance can introduce delay and small inter-finger differences.

① Refined tendon routing
Use low-friction guides, adjustable tensioners and improved anchoring to balance the cable pairs. ② Fabrication tolerances
Casting bubbles, channel inaccuracies and silicone variability affect stiffness and bending symmetry.

② More repeatable soft fabrication
Improve mold accuracy, vacuum-degas silicone and standardize curing/demolding conditions.
③ Seal-dependent suction
Suction performance depends on surface geometry and is currently driven by a manual vacuum source.

③ Autonomous suction control
Integrate a compact pump with pressure sensing to detect sealing and regulate vacuum automatically. ④ Qualitative validation
Performance is mainly evaluated by observing videos and grasp success, without force benchmarks.

④ Quantitative closed-loop testing
Measure bending angle, payload, pull-off force, success rate and durability over repeated cycles.

# Limitations & Future Work

Reduce mechanical variability and automate suction Next Steps and
Future Works | Waterproofing and validation in wet environments

# Thank you for your attention!

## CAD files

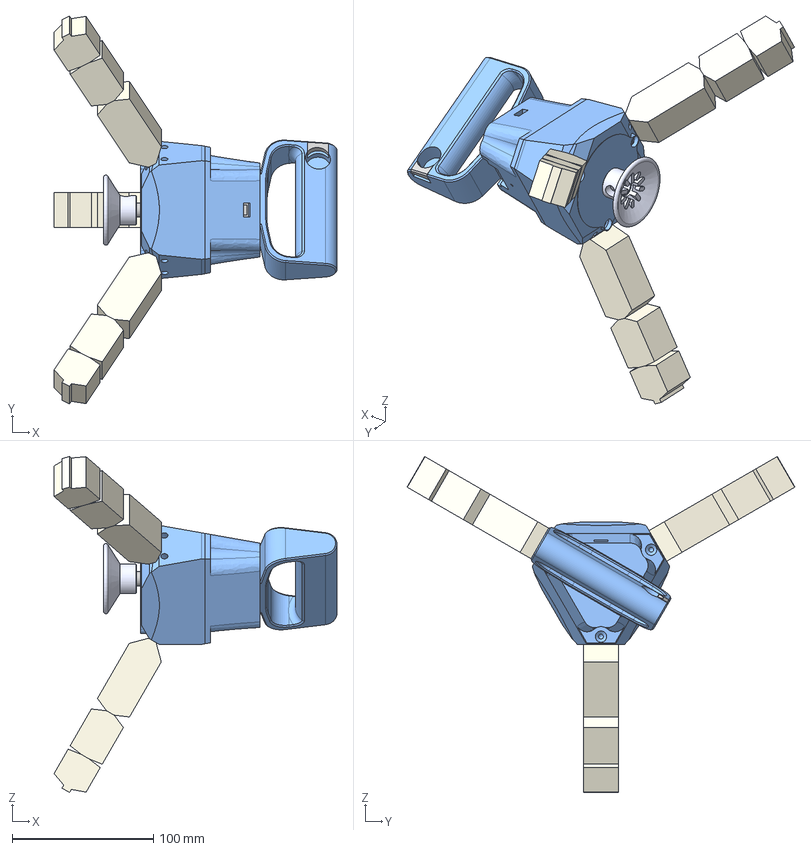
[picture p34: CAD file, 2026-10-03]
cad/step/AssemblySoft.step
200.2 x 274.6 x 237.8 mm
Spool
DiskAttach
suction_cup
Handle

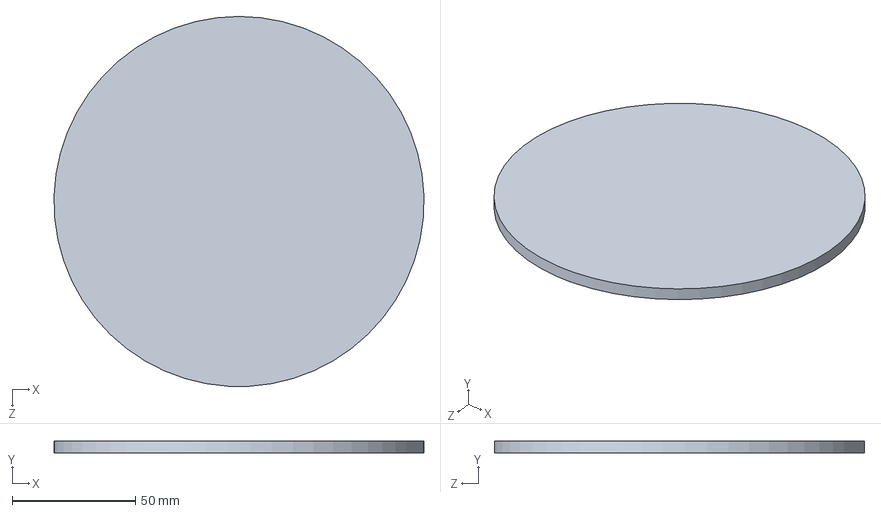
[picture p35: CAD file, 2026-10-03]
cad/solidworks/soft_project_assembly.SLDASM
149.9 x 5.00 x 150.0 mm

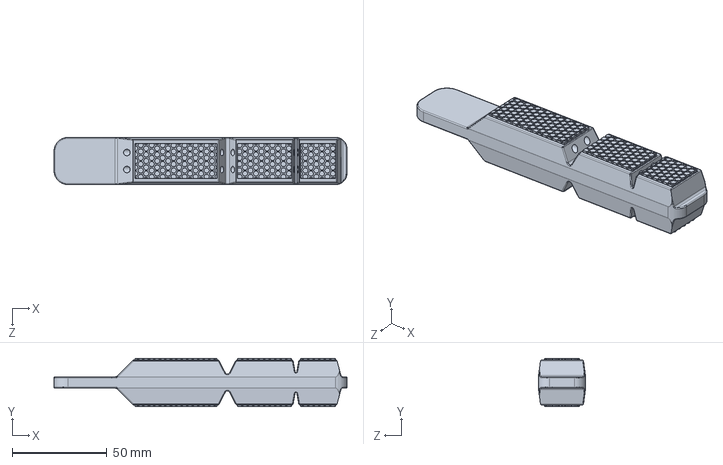
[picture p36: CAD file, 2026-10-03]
cad/solidworks/mold_fingers_fill_patt_v3_noBump_FINGER.SLDPRT
155.0 x 25.6 x 25.0 mm

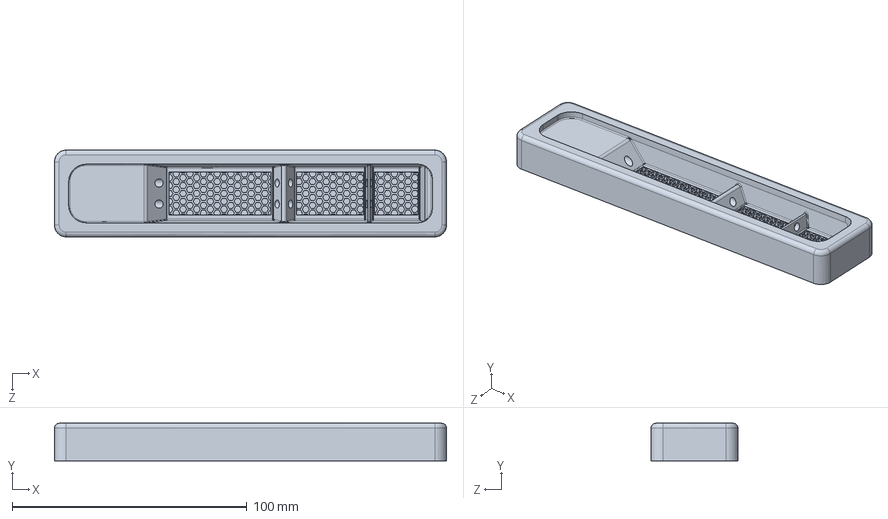
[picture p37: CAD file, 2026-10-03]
cad/solidworks/mold_fingers_fill_patt_v3_noBump.SLDPRT
167.0 x 16.0 x 37.0 mm

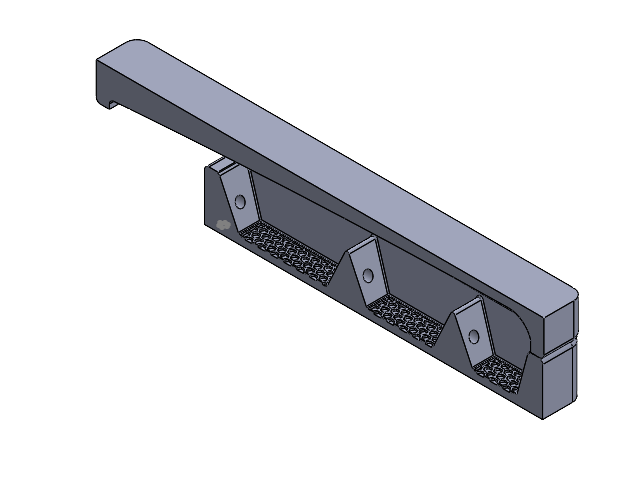
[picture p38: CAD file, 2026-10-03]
cad/solidworks/molds_preview.SLDASM
mold_fingers_fill_patt_onlyEco
mold_outer_finger

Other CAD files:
cad/solidworks/base.SLDPRT
cad/solidworks/AssemblySoft.SLDASM

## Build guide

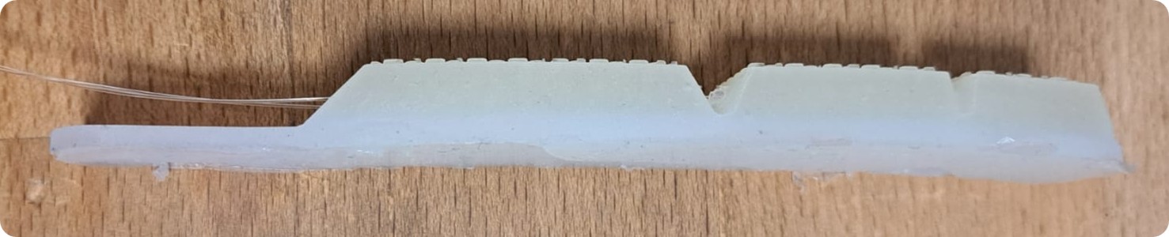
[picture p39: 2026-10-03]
media/fabrication/First prototype of a half of a finger.jpg
